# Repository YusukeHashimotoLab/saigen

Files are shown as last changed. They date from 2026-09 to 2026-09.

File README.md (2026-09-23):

# SAIGEN

**SAIGEN** — **S**tandardized **A**utomation **I**nfrastructure for **G**eneralizable
**E**xperiment reproductio**N** (also *saigen*, 再現, Japanese for "reproduction").

A simple, easy-to-introduce, open-source platform for automated materials-synthesis
experiments, focusing on **reliable automation and quantitative process recording**
rather than full autonomy.

Repository: https://github.com/YusukeHashimotoLab/saigen

A manuscript describing the platform and its ZIF-8 demonstration is in preparation
(working title: *Quantitative control and improved reproducibility of materials
synthesis processes using an automated experimentation platform*). It is referred to
as "the paper" throughout this repository; a citation will be added here once it is
available.
<!-- TODO: add the citation / DOI when the manuscript is published, and add a
     preferred-citation block to CITATION.cff. -->

The platform combines commercially available instruments (robot arms, electric
pipettes, web cameras, an electronic balance) with 3D-printed fixtures, and operates
them with control code generated by an AI agent based on a large language model (LLM).
As a demonstration, ZIF-8 (a metal–organic framework) was synthesized with a
two-solution mixing system, and the dependence of its particle size distribution on
the solution dispensing speed was quantified and reproduced.

**Video:** the two-solution mixing system built on this platform, in operation:
https://youtu.be/5X2-4LuQfns

## Repository layout

| Path | Contents |
|---|---|
| `src/agent/` | AI agent that generates JSON experimental flows from natural language (Gemini API or any OpenAI-compatible endpoint) and the preset flows |
| `src/devices/` | Control drivers for each instrument (robot arm, electric pipette, hot-plate stirrer, electronic balance, webcam) and the safety wrapper the flows run through |
| `src/flow/` | Schema, validator, executor and command-line runner for the JSON experimental flow format |
| `src/gui/` | Browser-based GUI for parameter input and flow confirmation |
| `src/voice/` | Voice input (whisper-large-v3-turbo) |
| `src/monitoring/` | IoT sensor logging (Raspberry Pi + Environment Sensor HAT) and process cameras |
| `src/imaging/` | Appearance-imaging system: NEEWER RGB62 light + Logitech C920n camera control, white/red/green/blue capture sequence, cropped-image comparison and depth-direction transmitted-light profiles (paper Figure 6) |
| `detection/` | Object detection based on YOLOv8 — **kept separate for licensing reasons, see below** |
| `cad/` | CAD design bank of 3D-printable experimental components (STL + editable Fusion 360 sources) |
| `docs/` | Bill of materials, setup guide, experimental-flow format reference, spreadsheet-input guide, guide to adding an instrument |
| `examples/zif8/` | Sample experimental flows of the ZIF-8 demonstration (JSON equivalents of the spreadsheet sequence) and monitoring CSV templates |
| `examples/microscope/` | Example flow that photographs the product with the USB digital microscope (`capture_microscope`) |
| `examples/dispensing_stability/` | Measured data of the 100-shot dispensing-repeatability test and the script that recorded it |

## Getting started

1. See [`docs/bom.md`](docs/bom.md) for the full list of hardware used.
2. Print the fixtures in `cad/` (STL files; the Fusion 360 sources are included for
   modification — see [`cad/README.md`](cad/README.md)).
3. Follow [`docs/setup.md`](docs/setup.md) to connect the instruments to the control PC.
4. Copy `config.example.yaml` to `config.yaml` and set the COM ports and workspace
   limits of your own cell; copy `.env.example` to `.env` and set your API keys.
   **Never commit `.env` or `config.yaml`.**
5. Install the Python dependencies: `pip install -r requirements.txt`
   (module-specific notes, e.g. for the imaging system, are in each `src/<module>/README.md`).
   Check the installation with `pytest tests/` — the suite needs no hardware.
6. After every power-on, home each arm once so the firmware's joint angles match the
   real arm (`python -m src.devices.dobot.home_dobot --robot 1 --mock` to rehearse,
   then without `--mock`; the arm sweeps to its joint-1 end stop, so clear the area).
   Then dry-run a flow without hardware, then run it for real. The ZIF-8 examples are the
   JSON equivalents of the spreadsheet sequence in step 7, which is the path the
   paper's batches were actually run with:

   ```bash
   python -m src.flow.run_flow examples/zif8/zif8_two_solution_mixing_speed5.json --mock
   python -m src.flow.run_flow examples/zif8/zif8_two_solution_mixing_speed5.json
   ```

   Every move is checked against the `workspace` limits in `config.yaml` before the
   robot is commanded — in `--mock` mode too. Ctrl+C is an emergency stop: the arm
   halts where it is rather than driving home. Each run leaves
   `logs/<date>/<flow>_<time>/` with `run.log`, `measurements.csv`, `summary.md`,
   `metadata.json` and a copy of the flow; add `--no-record` to skip the sensor-CSV
   and video recording that real runs start by default.

7. Or set the parameters in a spreadsheet — **this is the path used for the paper's
   ZIF-8 experiments**: the two-solution mixing experiment (shown in the
   [video](https://youtu.be/5X2-4LuQfns) above) runs from a
   `parameter,value,note` CSV, with no JSON at all:

   ```bash
   cp src/flow/csv_runner/control.example.csv src/flow/csv_runner/control.csv
   python -m src.flow.csv_runner.run_csv --mock   # then without --mock for a real run
   ```

   The sheet is range-checked before any device is opened, the generated steps go
   through the same schema and workspace validator as a JSON flow, and the run leaves
   the same log folder; see [`docs/csv-runner.md`](docs/csv-runner.md).

8. Or use the GUI, where flows can also be generated from natural language or voice
   (the reported ZIF-8 batches did not use this path):

   ```bash
   streamlit run src/gui/app.py
   ```

   Ports come from `config.yaml` and stay editable in the sidebar; the flow is
   validated against the same schema before any device is opened, *Mock* runs it
   end to end without hardware, *Stop* aborts through the same emergency-stop path
   as Ctrl+C, and the run leaves the same `logs/<date>/…` folder as the CLI.

## Using SAIGEN with an AI coding agent

The intended way to adopt SAIGEN is to clone (or download) the repository, open it
in an AI coding agent such as Claude Code, Codex or Cursor, and let the agent adapt
it to your hardware in conversation. [`CLAUDE.md`](CLAUDE.md) (identical to
[`AGENTS.md`](AGENTS.md)) tells the agent how the repository is organised, how to
verify changes without hardware, and what it must not do on its own — in particular,
it must never start a real run or loosen the workspace limits without you asking.
A first message that works well:

> Read CLAUDE.md, then help me adapt this platform to my hardware: one Dobot Magician
> on COM3 with a Picus 2 pipette on COM4, a BCE8221 balance on COM8 and no second robot.
> Validate and mock-run an example flow when you are done.

Everything the agent does is also available by hand through the steps above.

The flow format is described in [`docs/experimental-flow.md`](docs/experimental-flow.md),
the spreadsheet input in [`docs/csv-runner.md`](docs/csv-runner.md), and adding an
instrument to the platform in [`docs/adding-an-instrument.md`](docs/adding-an-instrument.md); the ZIF-8 flows —
JSON equivalents of the spreadsheet sequence the paper's batches were run with — are in
[`examples/zif8/`](examples/zif8/).

## Licensing

- **Code** (`src/`, `examples/`): MIT License — see [`LICENSE`](LICENSE). Third-party components are listed in [`THIRD_PARTY_NOTICES.md`](THIRD_PARTY_NOTICES.md).
  The robot-arm driver uses [pydobot](https://github.com/luismesas/pydobot)
  (Copyright 2017 Luis Mesas, MIT License) with a small patch in
  `src/devices/dobot/pydobot_patch.py`. The vendor SDK (DobotDll) is **not** used and
  is not included in this repository.
- **CAD models and documentation** (`cad/`, `docs/`): Creative Commons Attribution 4.0
  (CC BY 4.0, https://creativecommons.org/licenses/by/4.0/); the CAD-specific notes are in
  [`cad/README.md`](cad/README.md).
- **Object detection** (`detection/`): depends on [Ultralytics YOLOv8](https://github.com/ultralytics/ultralytics),
  which is licensed under **AGPL-3.0**. This module is therefore isolated from the
  MIT-licensed code and is distributed under AGPL-3.0. The rest of the platform runs
  without it (object detection is an optional monitoring feature).

The fine-tuned YOLOv8 weights and the training images are **not** included in this
repository. `detection/README.md` describes how to fine-tune your own model for your
setup.

## Disclaimer

SAIGEN is research software, shared so that others can reproduce and build on our
work. It is provided "as is", without warranty of any kind; the full terms are in
[`LICENSE`](LICENSE) for the code and in Section 5 of CC BY 4.0 for the CAD models and
documentation. The authors and their institutions accept no liability for injury,
damage to equipment, loss of samples or data, or any other loss arising from its use.

- **It moves hardware and handles chemicals.** A real run drives robot arms, dispenses
  liquids and may heat and stir them. Anyone running it is responsible for their own
  risk assessment, for following the safety rules of their institution and the safety
  data sheets of their reagents, and for supervising the cell while it operates.
- **The safety layer is not a certified safety system.** The workspace validators and
  the emergency stop reduce the chance of a collision inside the limits *you*
  configure. They are not a substitute for guarding, a hardware emergency stop or
  the manufacturers' instructions, and they know nothing about what is actually on
  the bench. Measure your own cell, set your own limits, and always do a mock run
  and a supervised dry run before using reagents.
- **Review generated flows and code.** Flows drafted by the LLM agent, and changes
  made by an AI coding agent, can be wrong in ways that validation does not catch
  (a wrong volume, vial or temperature is still a valid flow). Read them before a
  real run.
- **The CAD models are untested outside our laboratory.** They were designed for our
  instruments and printers; strength, fit, heat resistance and chemical resistance
  depend on your material and print settings and are not guaranteed.
- **No affiliation.** SAIGEN is not affiliated with, endorsed by or supported by the
  manufacturers of the instruments it controls. Product names are trademarks of their
  respective owners. Using this software may fall outside an instrument's intended use
  and may affect its warranty; check with the manufacturer.

## Citing

If you use SAIGEN, please cite the software using the metadata in
[`CITATION.cff`](CITATION.cff) (GitHub's "Cite this repository" button). A paper
citation will be added once the manuscript above is published.

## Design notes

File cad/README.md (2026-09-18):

# CAD design bank

3D-printable experimental components. All models were designed with Autodesk
Fusion 360 and printed on a Bambu Lab X1E.

**License: CC BY 4.0** (https://creativecommons.org/licenses/by/4.0/).
You may share and adapt these models, including commercially, with attribution
to the designers listed below and to the paper (see repository README).

## Gallery

Click a picture to open the STL in GitHub's built-in 3D viewer, where the model
can be rotated and zoomed in the browser.

<table>
<tr>
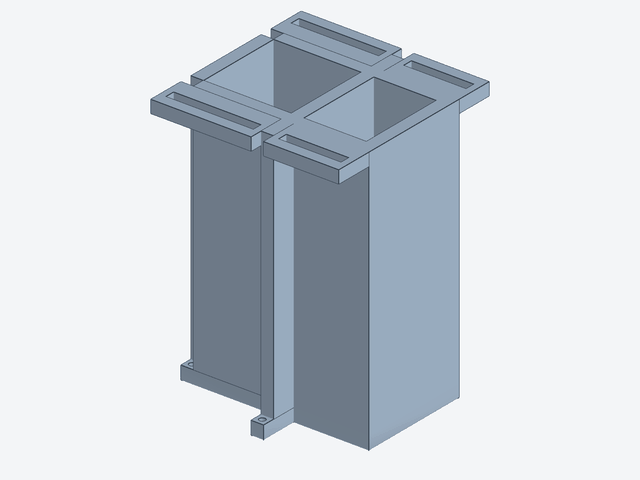
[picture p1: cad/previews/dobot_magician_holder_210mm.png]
Robot-arm pedestal
<td align="center" width="33%"><br><b>Robot-arm pedestal</b><br><sub>150 × 150 × 211 mm · <a href="robot-arm-holder/dobot_magician_holder_210mm.stl">3D view</a></sub></td>
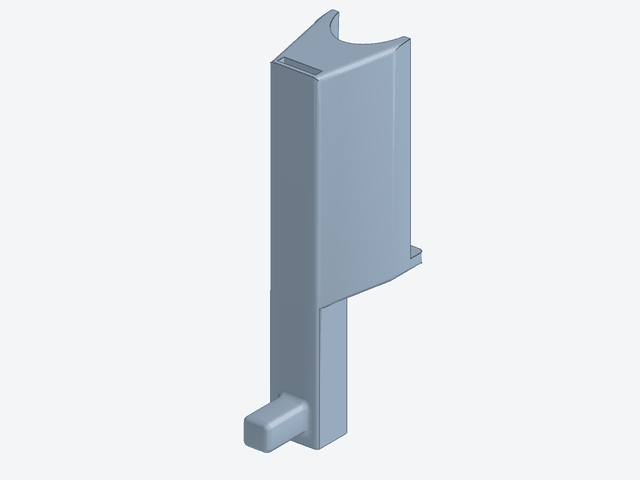
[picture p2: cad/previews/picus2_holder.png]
Pipette holder (Picus 2)
<td align="center" width="33%"><br><b>Pipette holder (Picus 2)</b><br><sub>32 × 67 × 135 mm · <a href="pipette-holder/picus2_holder.stl">3D view</a></sub></td>
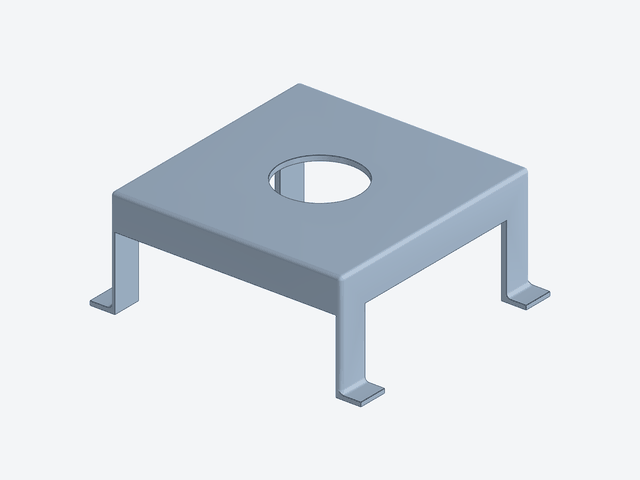
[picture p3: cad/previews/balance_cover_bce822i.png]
Balance cover (BCE822i)
<td align="center" width="33%"><br><b>Balance cover (BCE822i)</b><br><sub>275 × 240 × 109 mm · <a href="balance-cover/balance_cover_bce822i.stl">3D view</a></sub></td>
</tr>
<tr>
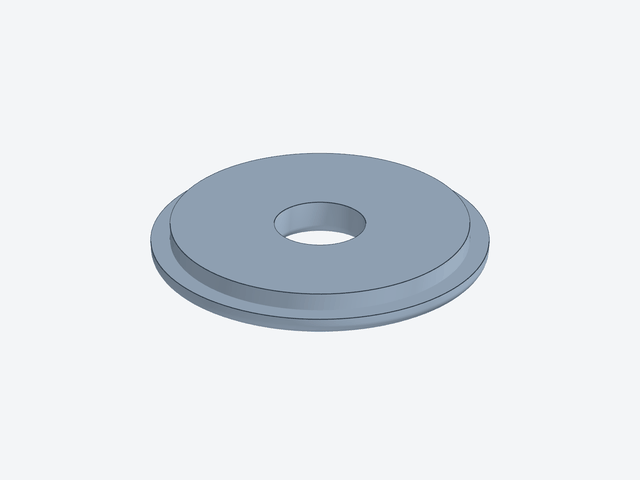
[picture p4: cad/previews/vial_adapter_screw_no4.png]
Adapter: No. 4 screw-cap vial
<td align="center" width="33%"><br><b>Adapter: No. 4 screw-cap vial</b><br><sub>92 × 92 × 10 mm · <a href="balance-cover/adapters/vial_adapter_screw_no4.stl">3D view</a></sub></td>
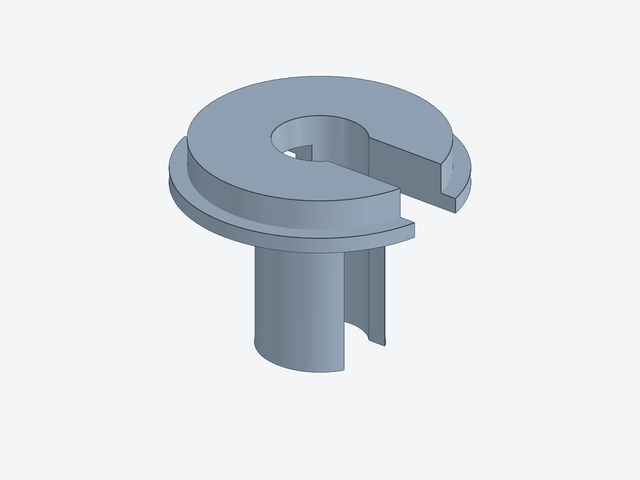
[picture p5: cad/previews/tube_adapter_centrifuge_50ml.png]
Adapter: 50 mL centrifuge tube
<td align="center" width="33%"><br><b>Adapter: 50 mL centrifuge tube</b><br><sub>90 × 92 × 70 mm · <a href="balance-cover/adapters/tube_adapter_centrifuge_50ml.stl">3D view</a></sub></td>
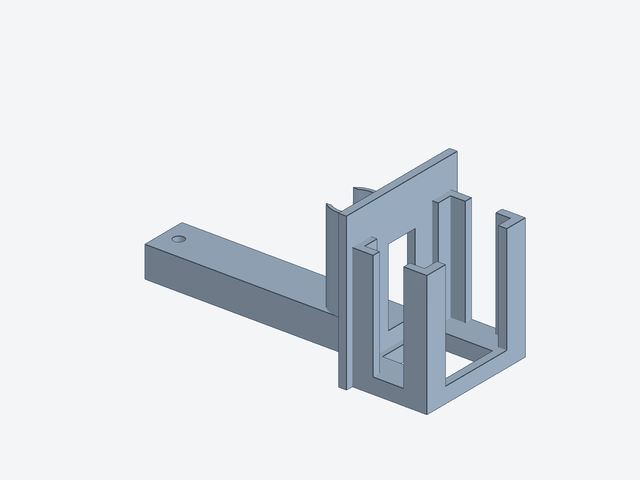
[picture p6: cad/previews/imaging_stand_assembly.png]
Imaging stand
<td align="center" width="33%"><br><b>Imaging stand</b><br><sub>204 × 90 × 100 mm · <a href="imaging-stand/imaging_stand_assembly.stl">3D view</a></sub></td>
</tr>
<tr>
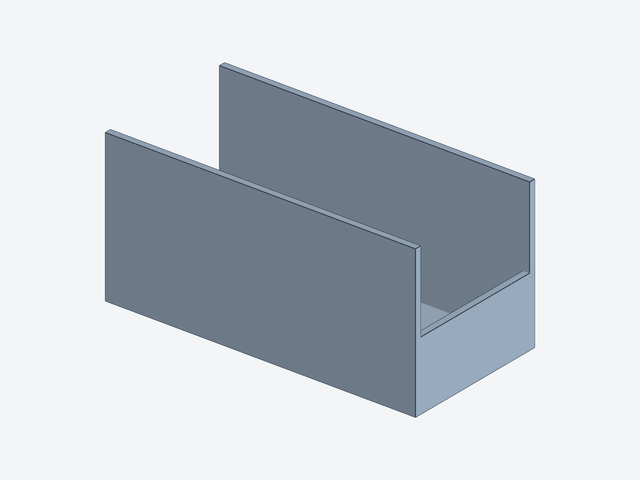
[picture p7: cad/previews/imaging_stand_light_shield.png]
Imaging-stand light shield
<td align="center" width="33%"><br><b>Imaging-stand light shield</b><br><sub>250 × 120 × 120 mm · <a href="imaging-stand/imaging_stand_light_shield.stl">3D view</a></sub></td>
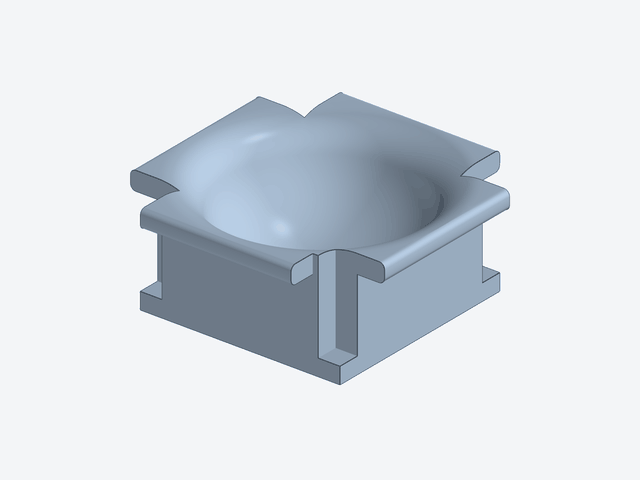
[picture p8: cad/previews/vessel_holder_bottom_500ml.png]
Vessel holder, base (500 mL)
<td align="center" width="33%"><br><b>Vessel holder, base (500 mL)</b><br><sub>140 × 140 × 59 mm · <a href="vessel-holder/vessel_holder_bottom_500ml.stl">3D view</a></sub></td>
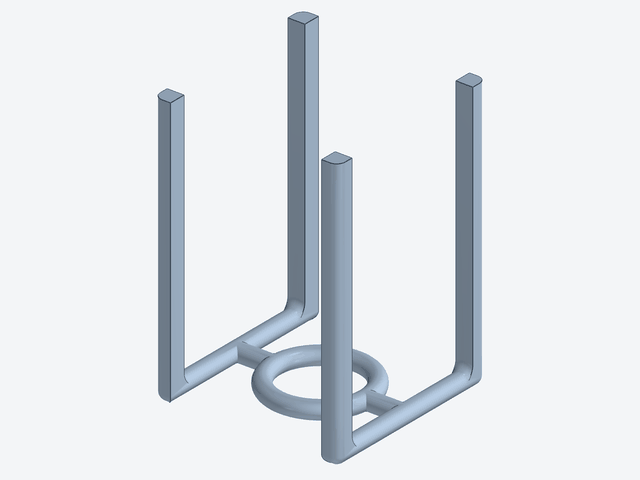
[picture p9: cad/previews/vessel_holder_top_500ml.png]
Vessel holder, upper frame (500 mL)
<td align="center" width="33%"><br><b>Vessel holder, upper frame (500 mL)</b><br><sub>110 × 110 × 160 mm · <a href="vessel-holder/vessel_holder_top_500ml.stl">3D view</a></sub></td>
</tr>
</table>

<p align="center">
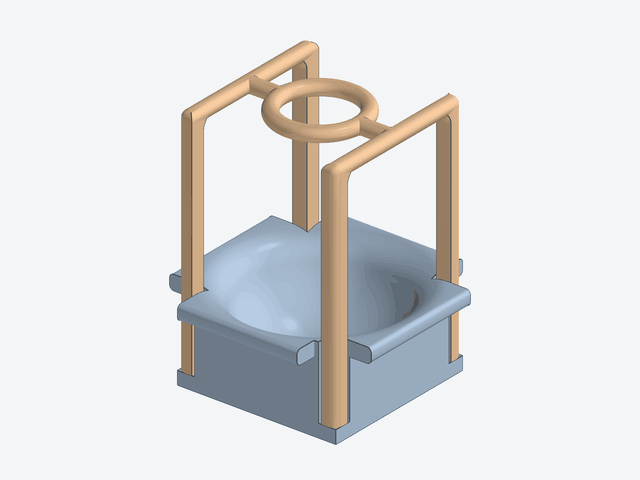
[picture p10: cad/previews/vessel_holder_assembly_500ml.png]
Vessel holder assembled
<br>
<sub>Vessel holder assembled: the upper frame (shown in a second colour) is turned
over and its four posts slide down the corner grooves of the base.</sub>
</p>

## Designers

| Designer | Affiliation | Contact | Components |
|---|---|---|---|
| Takaya Muramoto (村元貴哉) | Graduate School of Engineering, Tohoku University | muramoto.takaya.s1@dc.tohoku.ac.jp | `pipette-holder/` |
| Yusuke Hashimoto (橋本佑介) | Frontier Research Institute for Interdisciplinary Sciences, Tohoku University | yusuke.hashimoto.b8@tohoku.ac.jp | `robot-arm-holder/`, `balance-cover/` (cover and adapters), `imaging-stand/` |

Questions about a model, or corrections to it, go to its designer.

## Components

Every part is provided as a binary STL (millimetres, exported from Fusion 360),
ready to slice, and — where available — as the editable Fusion 360 source.
Bounding boxes are taken from the meshes.

| Directory | Component | Print file | Editable source | Size X × Y × Z (mm) | Designer |
|---|---|---|---|---|---|
| `robot-arm-holder/` | Pedestal that fixes the robot arm (Dobot Magician) to the bench and raises it by 210 mm | `dobot_magician_holder_210mm.stl` | `dobot_magician_holder_210mm.f3d` | 150 × 150 × 211 | Y. Hashimoto |
| `pipette-holder/` | Holder fixing the electric pipette (Sartorius Picus 2) to the robot arm tip | `picus2_holder.stl` | `picus2_holder.f3d` | 32 × 67 × 135 | T. Muramoto |
| `balance-cover/` | Liquid-splash cover for the electronic balance (Sartorius BCE822i), with windshield; its top plate has a Ø82 mm opening for the vessel adapters below | `balance_cover_bce822i.stl` | `balance_cover_bce822i.f3d` | 275 × 240 × 109 | Y. Hashimoto |
| `balance-cover/adapters/` | Vessel adapter for the cover opening: ring for a No. 4 screw-cap vial (13.5 mL; e.g. AS ONE 9-852-06), Ø25 mm chamfered hole | `vial_adapter_screw_no4.stl` | `vial_adapter_screw_no4.f3d` | 92 × 92 × 10 | Y. Hashimoto |
| `balance-cover/adapters/` | Vessel adapter for the cover opening: sleeve for a 50 mL centrifuge tube, Ø30 mm bore | `tube_adapter_centrifuge_50ml.stl` | `tube_adapter_centrifuge_50ml.f3d` | 90 × 92 × 70 | Y. Hashimoto |
| `imaging-stand/` | Holding stand for the appearance-imaging system (light, sample, camera) | `imaging_stand_assembly.stl` (one mesh of the whole assembly) | `imaging_stand_assembly.f3z` (Fusion archive: stand, assembly and light fixture designs) | 204 × 90 × 100 | Y. Hashimoto |
| `imaging-stand/` | Light shield placed over the imaging stand | `imaging_stand_light_shield.stl` | `imaging_stand_light_shield.f3d` | 250 × 120 × 120 | Y. Hashimoto |
| `vessel-holder/` | Two-part holder for a 500 mL round-bottom vessel, base: block with a spherical seat (Ø105 mm) and a groove at each corner for the posts of the upper frame | `vessel_holder_bottom_500ml.stl` | `vessel_holder_bottom_500ml.f3d` | 140 × 140 × 59 | <!-- TODO: designer --> |
| `vessel-holder/` | Two-part holder for a 500 mL round-bottom vessel, upper frame: four 10 mm posts joined by a ring (Ø44 mm bore) that surrounds the vessel neck. The frame gives a robot arm or a lift something to hook, so that the holder can be carried with the vessel in it; exported ring-down, used ring-up | `vessel_holder_top_500ml.stl` | `vessel_holder_top_500ml.f3d` | 110 × 110 × 160 | <!-- TODO: designer --> |

Notes:

- The two vessel adapters share the same seat: a Ø92 mm flange resting on the top
  plate of the balance cover and a Ø81 mm spigot that drops into its Ø82 mm opening,
  so they are interchangeable without modifying the cover. Print one per vessel
  type you use.
- `.f3d` is a single Fusion 360 design; `.f3z` is a Fusion 360 archive that bundles
  an assembly with the designs it references. Open either with *File → Open* in
  Fusion 360 (upload to your project).
- The meshes were checked to be closed (no open edges). `dobot_magician_holder_210mm.stl`
  is exported from a multi-body design, so a few internal faces are shared between
  touching bodies; slicers merge these, but re-export from the `.f3d` if your tool
  complains about non-manifold edges.
- The original file names were Japanese; they were renamed to ASCII for portability.
  Same geometry.
- The pictures in `previews/` are rendered from the STL files by
  [`tools/render_previews.py`](tools/render_previews.py) (needs `pyvista` and `pillow`);
  re-run it after adding or changing a part.
- The upper frame of the vessel holder rests on the 9 mm ledges at the foot of the
  corner grooves, which puts its ring about 160 mm above the bench. A round-bottom
  vessel cannot stand or be gripped on its own; the frame is the handling point
  when the vessel is moved by a robot arm or a lift.
- STEP exports are not included; export them from the `.f3d` / `.f3z` sources if you
  need a neutral format.

<!-- TODO: add recommended print settings (material, layer height, infill) per component. -->

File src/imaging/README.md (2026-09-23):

# Imaging module

Appearance-imaging system for SAIGEN, the automated experimentation platform (see the
[repository README](../../README.md) for the manuscript in preparation that this
module's results belong to). It backlights a sample vial with an RGB light,
photographs it under white, red, green and blue illumination with a fixed
camera, and turns those photographs into cropped side-by-side comparisons and
depth-resolved transmitted-light intensity profiles — the material behind the
paper's "Imaging system for appearance evaluation" section and Figure 6.

## System configuration

### Hardware

| Component | Model | Interface | Notes |
|---|---|---|---|
| Light | NEEWER RGB62 | Bluetooth LE | White (CCT) and single-colour (HSI) modes; controlled by [`neewer_light.py`](neewer_light.py) |
| Camera | Logitech C920n (HD Pro Webcam C920) | USB | Video + control abstracted by [`hw.py`](hw.py) |
| Holding stand | 3D-printed | — | Fixes the relative positions of light, vial and camera; STL and Fusion 360 sources in [`cad/imaging-stand/`](../../cad/imaging-stand/), together with a light shield placed over the stand |
| Control PC | — | — | Runs `camera_server.py`, `acquire.py`, `make_panel.py` |

See [`docs/bom.md`](../../docs/bom.md) for the full platform bill of materials.

### Geometry

The stand holds the light, sample vial and camera on one fixed optical axis so
every photograph is a backlit transmission image of the same region:

```
 NEEWER RGB62        sample vial            Logitech C920n
 (backlight)  -->  (screw-top vial,   -->  (USB, fixed focus
                    suspension below         and exposure)
                    clear supernatant)
   |____________________|____________________|
        all three fixed by the stand (cad/imaging-stand/)
```

### Software-fixed conditions

Imaging conditions are fixed in software rather than by hand, so repeated
photographs are comparable:

- **Camera** — [`config/camera_reference.json`](config/camera_reference.json)
  is the single source of truth: exposure 20 (macOS `exposure-time-abs`
  units; logged Windows equivalent `-9`), gain 0, focus 180, white balance
  4600 K manual. It stores this once per platform (macOS `uvc-util` control
  names under `"reference"`, Windows logical names under `"win32"`), applied
  through `hw.py`'s logical control names; `camera_server.py`'s `/api/health`
  and the acquisition scripts check the live camera against it. Every run
  records the settings **read back from the camera** at capture time
  (`camera_settings` in `summary.json`), not these reference constants.
- **Light** — [`config/light_reference.json`](config/light_reference.json)
  documents the illumination conditions used by `acquire.py`: a white CCT
  shot at 5600 K (used only for detecting the vial geometry; its brightness
  is auto-swept unless fixed with `--white-intensity`), and three HSI
  (single-colour) shots at hue 0° / 120° / 240° (red / green / blue), each at
  1 % intensity. This file is not read by any module at run time — it is a
  human-readable record of constants that are hard-coded in `acquire.py`.

**Two hard rules, both established by measurement on the C920:**

1. **White balance must stay manual at 4600 K. Never switch it back to
   auto.** The C920 has slow, hidden internal white-balance state; every time
   it is switched between auto and manual it settles into a different,
   non-reproducible colour state. Only an uninterrupted manual 4600 K holds a
   consistent colour balance.
2. **Changing exposure while the camera server's stream is running has no
   effect on the frames it serves.** The control write succeeds and reads
   back correctly, but the live MJPEG stream keeps using the exposure that
   was in effect when it started. To change exposure: set the new value,
   then restart `camera_server.py`. Adjusting brightness *during* a
   measurement should be done on the light, not the camera.

The three illumination wavelengths (625 / 525 / 465 nm) are the LED's
**nominal** values, not independently measured (±10-15 nm uncertainty); this
does not affect relative or time-series comparisons. Each single-colour LED
saturates its own dominant camera channel (red→R, green→G, blue→B) even at
1 % intensity, so photometry is always done on the **secondary** channel
(red→G, green→B, blue→G) — see `acquire.py`'s `COLORS` table and
`od_profile()`.

## Module map

| File | Role |
|---|---|
| [`paths.py`](paths.py) | Shared directory layout (`IMAGING_DATA_DIR`, `config/`, `examples/`) and `uvc-util` path resolution |
| [`hw.py`](hw.py) | Platform abstraction for the camera (macOS: ffmpeg + uvc-util; Windows: OpenCV/DirectShow) and the cross-platform measurement file lock |
| [`neewer_light.py`](neewer_light.py) | BLE control of the NEEWER RGB62 (CCT and HSI modes; macOS CoreBluetooth / Windows WinRT+bleak backends) |
| [`capture.py`](capture.py) | Thin HTTP client used by `acquire.py` to trigger captures and read/write camera controls through `camera_server.py` |
| [`camera_server.py`](camera_server.py) + [`static/`](static/) | Local web server (port 8799): live preview, camera/light controls, spot-measurement launcher, analysis viewer, and the HTML/JS front end |
| [`acquire.py`](acquire.py) | Capture sequence (white → red → green → blue) and the optical-density analysis (`od_profile`, sediment-front detection, figure generation) |
| [`geometry.py`](geometry.py) | Vial geometry detection from a white backlit photo (meniscus, cap, body, liquid bottom) |
| [`make_panel.py`](make_panel.py) | Publication panel figure: four cropped photographs plus the depth-resolved transmittance/OD curve |
| [`config/`](config/) | `camera_reference.json` (single source of truth for camera settings), `camera_local.example.json` (per-PC camera selection template), `light_reference.json` (documentation of the light constants) |
| [`examples/`](examples/) | One complete example run (see below) |

## Installation

From the repository root:

```bash
pip install -r requirements.txt
```

Platform-specific notes for this module:

- **macOS** — video comes from `ffmpeg` (AVFoundation) and camera control
  from `uvc-util`; both are external executables, **not bundled** here.
  Install `ffmpeg` with `brew install ffmpeg`; build `uvc-util` from
  [github.com/jtfrey/uvc-util](https://github.com/jtfrey/uvc-util) and put it
  on `PATH`, or point the `UVC_UTIL` environment variable at the binary (see
  `paths.uvc_util_path()`). The light backend uses PyObjC (`pyobjc-framework-CoreBluetooth`,
  `pyobjc-framework-libdispatch`), which `requirements.txt` installs on macOS only.
- **Windows** — video and camera control both go through OpenCV's DirectShow
  backend, which is why `requirements.txt` pins `opencv-python==4.12.0.88`:
  4.13+ (including 5.0) breaks get/set of `CAP_PROP_WHITE_BALANCE_BLUE_U` on
  the C920, the property used to hold the required manual 4600 K white
  balance. `pygrabber` (already listed) enumerates DirectShow devices and
  pulls in `comtypes` automatically. The light backend prefers piggybacking
  on an already-connected device via the `winrt` packages (not pinned) and
  falls back automatically to scanning with `bleak` (already listed) if they
  are absent. On a PC with more than one webcam, copy
  `config/camera_local.example.json` to `config/camera_local.json`
  (git-ignored) and set `win32_device_name`/`win32_device_path` to pick the
  C920 unambiguously — `hw.py` refuses to start on zero or multiple matches.
- **macOS camera selection** — ffmpeg opens the camera by name
  (`HD Pro Webcam C920`) and `hw.py` looks up the `uvc-util` index of that
  same name (`uvc-util -d`), so controls always go to the streamed camera;
  it refuses to start if the name is missing or matches more than one
  device.
- **The light** must be powered on before starting `camera_server.py`. On
  macOS, `neewer_light.py` piggybacks onto an existing BLE connection rather
  than opening its own, so it can share a connection already held by the
  NEEWER Control Center app instead of competing with it. If more than one
  NEEWER light is reachable, `neewer_light.py` refuses to guess: set
  `NEEWER_DEVICE_ID` in the repository's `.env` (or the environment) to part
  of the device id shown in the error message (macOS: peripheral UUID;
  Windows: WinRT device id or Bluetooth address). Every BLE write is
  checked; a device error or a missing acknowledgement aborts the command.
- **`IMAGING_DATA_DIR`** (environment variable) sets where captured photos
  and analysis output go. Default: `imaging_data/` at the repository root
  (`photos/` and `analysis/` subdirectories; see `paths.py`). The location is
  anchored to the module file, not to the current directory, so the camera
  server and a hand-run `acquire.py` always write to the same place. A
  relative value is resolved against the directory the server was started
  from, and the server passes the resolved path (and its actual `--port`,
  as `IMAGING_SERVER_URL`) to the `acquire.py` child it launches.

## Usage

### 1. Start the camera server

```bash
python camera_server.py
```

Open `http://localhost:8799`. The page has five tabs:

- **Camera** — sliders for exposure, gain, focus and white balance (Kelvin),
  auto-exposure/auto-focus/auto-white-balance toggles, and a manual
  **Capture** button; a warning banner reminds you to keep white balance
  manual at 4600 K, and flags that exposure changes need a server restart to
  reach the live preview. While a measurement holds the lock, control writes
  from this tab (or any other client) are refused with HTTP 409; only the
  running acquisition, which registers an owner token, may write.
- **Light** — On/Off, and either White (CCT: brightness + colour temperature)
  or Monochrome (HSI: hue + saturation + brightness, with quick Red 625 /
  Green 525 / Blue 465 buttons) control.
- **Measure** — a named spot measurement: Full (white+RGB) or White-only
  mode, folder and sample name, and toggles for a locked frame, fixed
  monochromatic LED intensity, or fixed white LED intensity (white-only
  mode). This is the UI front end for `acquire.py`, run as a subprocess and
  polled via `/api/spectral/status`.
- **Analysis** — a Refresh button and the most recent run's `spectral.png`.
- **Conditions** — one-shot frame (geometry) calibration, and named presets
  that save/apply/verify a full camera+light+geometry configuration.
  Applying a preset checks every camera write and reads the settings back;
  a failed write or a differing read-back is reported and the light and
  geometry are left untouched. If the stream is stale afterwards (macOS),
  the response says the server must be restarted before measuring: per
  rule 2 above, neither the live view nor captured photos see the change
  until then.

### 2. Apply and verify the reference camera settings

Set the camera to the values in `config/camera_reference.json` (exposure 20 /
gain 0 / focus 180 / white balance manual 4600 K) using the Camera tab or the
`/api/control` endpoint, then confirm with:

```bash
curl http://localhost:8799/api/health
```

`matches_reference` should be `true`; `mismatches` lists any control that
differs from `camera_reference.json`, and `stream_settings_stale` flags the
"exposure changed but the stream didn't update" condition described above.

### 3. Acquire a run

```bash
python acquire.py --folder <experiment> --name <sample>
```

This drives the light through white → red → green → blue, capturing one
photo per step through the running `camera_server.py`, and writes the run to
`<IMAGING_DATA_DIR>/photos/<experiment>/<sample>/`. Before the first photo it
fixes and reads back the white balance, then queries `/api/health` and
**aborts if the stream is stale** (settings changed after the stream
started, e.g. white balance switched from auto on this run — restart the
server and run again), if there is no fresh frame, or if the controls
cannot be read. A mismatch against `camera_reference.json` is only a
warning (the reference exposure depends on the sample) but is recorded. Useful options (see
`python acquire.py --help` for the full list):

| Option | Effect |
|---|---|
| `--mode {full,white}` | `full` (default): white + red/green/blue, ~3-wavelength OD. `white`: a single white shot only, giving per-camera-channel (R/G/B) OD — quicker, but only valid for named runs |
| `--white-intensity PCT` | Fix the white-shot LED intensity (white-only mode only) so multiple samples are photographed under identical illumination, for photo comparison or absolute-transmittance comparison |
| `--fixed-intensity` | Disable automatic monochromatic-LED intensity adjustment and hold it at `--intensity` (for cross-sample absolute comparison) |
| `--calibrate` | Detect the vial geometry once from a white reference and save it as a locked frame |
| `--locked` | Skip per-run geometry auto-detection and reuse the locked frame (for comparing swapped-in samples without shifts in field of view) |
| `--intensity`, `--restore` | Initial monochromatic LED intensity (default 1 %) and the light state to leave the light in when done (default: off) |

### 4. Run directory format

Each run directory contains:

| File | Contents |
|---|---|
| `ref_white.jpg` | White-light reference photo (geometry detection; also the photometry image itself in white-only mode) |
| `shot_red.jpg`, `shot_green.jpg`, `shot_blue.jpg` | Monochromatic captures (full mode only) |
| `profiles.csv` | Per-row optical density, one column per wavelength/channel (`od_625`/`od_525`/`od_465` in full mode, `od_R`/`od_G`/`od_B` in white-only mode), each followed by `od_<label>_cap`, the uncorrected profile computed with the cap pedestal alone (identical when `pedestal_mode` is `cap`) |
| `spectral.png` | OD-vs-depth figure generated by `acquire.py` at capture time |
| `summary.json` | Geometry (`meniscus_y`, `liquid_bottom_y`, `body_x0`/`x1`, `fill_fraction`), per-wavelength intensity/channel/warning plus `pedestal_rule`, `i0` and `analysis_warning`, `sediment_front_y`, `white_balance_fixed` (commanded), `camera_settings` (read back before the first photo), `camera_settings_after` / `camera_settings_changed` (read back after the last), `camera_device`, `camera_matches_reference`/`camera_mismatches`, and measured headspace brightness used to cross-check actual light intensity. Written before the figure, so a plotting failure never loses it; never contains NaN/inf |

### 5. Make the publication panel

```bash
python make_panel.py examples/zif8_vial_5s --out panels
```

Outputs `<run_dir name>_panel.png` (300 dpi), `_panel.pdf`, and a draft
`_caption.md`, all under `--out` (default `./panels`) — `make_panel.py` never
writes into the run directory itself. Options (`python make_panel.py --help`):

| Option | Effect |
|---|---|
| `--y {transmittance,od}` | Right-panel x-axis: transmittance `T = 10^-OD` (default) or OD directly |
| `--with-white` | Also draw the white (G-channel) curve in the depth panel; omitted by default |
| `--mm-per-px MM` | Show the depth axis in millimetres (5 mm steps) instead of pixel rows |

The panel shows four cropped photographs (white, 625, 525, 465 nm, cap bottom
to vial bottom, all cropped to the same rectangle) beside a depth-resolved
transmittance/OD curve that shares the same vertical (pixel-row) scale as the
photographs, so visual features in the photos line up with inflections in the
curve. The white photograph is not plotted as a curve by default: its green
channel is saturated over a clear supernatant (the sensor clips before the
signal can be used quantitatively), so it is shown only as a visual
reference; `--with-white` draws it anyway (as a plain solid line). A
clip table for all four channels — per row, the fraction of pixels at
sRGB >= 250 in the inner 60 % of the body columns, summarised over the
liquid rows — is always printed to stdout regardless of that flag.

The draft caption is built from the run's `summary.json` (LED intensities,
the camera settings and device read back at capture time) and from those
measured clip fractions. Anything the run did not record is written as
"unknown" — e.g. the included example predates the camera read-back, so its
caption says the exposure is unknown rather than quoting the reference.

## Correspondence with paper Figure 6

| Figure 6 panel | Produced by |
|---|---|
| (a) appearance of the imaging system | The stand ([`cad/imaging-stand/`](../../cad/imaging-stand/)) and camera/light hardware described in [System configuration](#system-configuration) above |
| (b) a photograph taken with it | `examples/zif8_vial_5s/ref_white.jpg`, captured by `camera_server.py` via `acquire.py` |
| (c) sample images under white/red/green/blue illumination | The four cropped photo columns produced by `make_panel.py` from that same run |
| (d) depth profile of the transmitted-light intensity | The depth-resolved transmittance/OD curve in `make_panel.py`, computed from `profiles.csv` (written by `acquire.py`'s `od_profile()`) |

One example run is included, [`examples/zif8_vial_5s/`](examples/zif8_vial_5s/)
— the run behind those Figure 6 panels. It is a ZIF-8 suspension (white
sediment below a clear supernatant) synthesised by the platform in a
screw-top vial without stirring, with the second precursor solution
("solution 2") dispensed over 5 s, and photographed on 2026-07-14 at 13:25,
twelve days after synthesis.

It is included as a **worked example of the pipeline, not as a validated
measurement**, and it is not a dispensing-time comparison: it is a single
run at a single dispensing time. Its white reference and its 465 nm channel
are both sensor-clipped over the clear supernatant, and it predates the
reference camera exposure, so absolute transmittance is not comparable
across runs. [`examples/README.md`](examples/README.md) lists these caveats
in full — read it before reusing the numbers.

Figure 8 of the paper (nine vials, three per dispensing time) was **not**
taken with this imaging stand and is not reproduced by anything in this
directory.

## Analysis method

`acquire.py`'s `od_profile()` computes, for each wavelength/channel, a
depth-resolved optical density `OD(y) = -log10(I(y)/I0)`:

- Pixel values come from the secondary colour channel, averaged over the
  inner 60 % of the vial body's columns (avoiding light piped along the
  glass wall), then sRGB-linearised (inverse gamma) before any arithmetic.
- `I0` is the peak transmitted-light level just below the meniscus (past the
  refractive dip the curved liquid surface produces).
- A pedestal (lens flare + dark current) is normally estimated from the dark
  region above the cap; if attenuation is deep enough that the signal pins to
  stray light instead of continuing to fall, a flat low-value window further
  down is used as the floor instead and the curve is truncated there (a
  lower bound on OD only). Which rule chose the pedestal is recorded
  (`pedestal_rule`: `cap`, `flat_window` or `min_then_rise`); the
  minimum-then-rise rule is a heuristic, so it adds an `analysis_warning`,
  and the uncorrected cap-pedestal profile is saved next to the corrected
  one for comparison.
- A uniformly dark image, or a geometry that does not fit the image, gives
  an empty profile with a warning instead of aborting the run.
- The sedimentation front is the shallowest depth where the 625 nm OD rises
  above a fixed threshold for a sustained run of rows.

## Limitations / notes

- The 625 / 525 / 465 nm wavelengths are the LED's nominal values, not
  independently measured (±10-15 nm); verify with a spectrometer or
  diffraction grating before using them quantitatively rather than for
  relative/time-series comparison.
- The geometry detector (`geometry.py`) and the fixed-frame comparison mode
  assume a single vial on a fixed optical axis; it is not a general-purpose
  multi-sample imaging pipeline.
- Camera behaviour (the white-balance hidden state, the live-exposure
  pitfall, per-channel saturation under single-colour LEDs) is specific to
  the Logitech C920/C920n and was established by measurement on that
  camera; a different webcam model may not share these quirks — or may have
  different ones.
- This is a photographic transmission measurement, not a calibrated
  spectrophotometer: optical density values are useful for relative and
  time-series comparison under matched conditions, not as absolute
  extinction coefficients.

## License

MIT, as the rest of `src/` — see [`LICENSE`](../../LICENSE).

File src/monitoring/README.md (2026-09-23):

# Monitoring

IoT environmental sensor logging and process video recording for the automated
synthesis platform. A Raspberry Pi Zero WH + Waveshare Environment Sensor HAT
pushes sensor readings to the control PC, where a small FastAPI service
records them (plus an overhead-camera AprilTag pose track) to CSV; a separate
OpenCV helper records the overhead-camera video itself.

## Overview

```
 ┌────────────────────┐        TCP :50001            ┌───────────────────────────────────┐
 │ Raspberry Pi        │  JSON Lines, ~10 Hz          │ Control PC                          │
 │ pi/pi_sensor_agent  │ ────────────────────────────>│ dashboard/launch_sensor_dashboard   │
 │  (I2C sensor reads)  │                              │  FastAPI :8000  +  TCP server :50001│
 └────────────────────┘                              │                                      │
                                                       │  latest_sensor_data ──┐              │
                                                       │                       ▼              │
                                                       │              recording_loop (100 ms) │
                                                       │                       │              │
                                                       │                       ▼              │
                                                       │              CSV (sensor + tags)     │
                                                       └───────────────────────────────────┘
                    browser (dashboard UI)                       ▲        ▲
                        │  camera frames                          │        │
                        └── POST /api/detect_tags ─────────────────┘        │
                        └── POST /api/upload_video (webm) ───────────────────┘

 src/flow/run_flow.py, src/gui/app.py or any external process
        │
        └── POST /api/start , POST /api/end  ────────► start/stop a recording session

 camera/video_recorder.py  (on the control PC, independent of the dashboard)
        └── OpenCV VideoCapture(camera_index) ──► .mp4 (overhead process video)
```

Two recording paths run independently:

1. **Sensor + AprilTag CSV logging** — `dashboard/launch_sensor_dashboard.py`
   receives sensor pushes over TCP, serves a browser dashboard over HTTP, and
   (while a recording session is active) writes one CSV row per Pi every
   100 ms plus AprilTag pose rows whenever the browser posts a camera frame
   to `/api/detect_tags`.
2. **Overhead video recording** — `camera/video_recorder.py` opens an OpenCV
   `VideoCapture` on the process camera and writes an `.mp4` on its own
   thread. It has no dependency on the dashboard and can be started/stopped
   independently (e.g. from `src/flow/run_flow.py`).

## Measured quantities

| Quantity | Sensor | I2C address | CSV column(s) |
|---|---|---|---|
| Temperature | BME280 | `0x76` | `temperature` (°C) |
| Humidity | BME280 | `0x76` | `humidity` (%RH) |
| Visible + IR light (raw, **not lux**) | TSL25911 | `0x29` | `lux_raw` (channel-0 count) |
| UV | LTR390 | `0x53` | `uvi` (UV index) |
| VOC | SGP40 | `0x59` | `voc_raw` (raw signal, not the VOC index) |
| 3-axis acceleration | ICM20948 | `0x68` | `acc_x`, `acc_y`, `acc_z` (g) |
| 3-axis angular velocity | ICM20948 | `0x68` | `gyro_x`, `gyro_y`, `gyro_z` (deg/s) |

**The magnetometer (AK09916, embedded in the ICM20948 package) is not read in
this version.** Only the ICM20948's accelerometer and gyroscope are used.

**UV column semantics changed on 2026-09-08.** Recordings made before that date
were taken with the LTR390 in ALS mode, in which the UVS data registers never
update, so their `uvi` column is `0` throughout. The Pi agent now initialises
the sensor in UVS mode (20-bit, gain 3, 1000 ms measurement rate) and `uvi`
holds a UV index as a float. The column name is unchanged so older CSV files
remain parseable. Because a 20-bit conversion takes 400 ms, the value updates
about once a second even though the agent samples every 100 ms.

**Humidity recorded before 2026-09-23 is wrong by a factor of 1024.** The Pi
agent's BME280 compensation shifted the Q22.10 result right by 22 bits (which
already gives whole %RH) and then divided by 1024 again, so the `humidity`
column of older recordings holds values between 0 and about 0.098 instead of
0-100 %RH. Multiplying an old value by 1024 recovers the humidity, but only to
1 %RH: the 22-bit shift had already dropped the fractional part, so every
recovered value is a whole number (rounded down). Recordings made with the
fixed agent carry the full resolution of 1/1024 %RH.

**The light column is a raw count, not lux, and was renamed on 2026-09-23.**
The value recorded as `lux` in older files was never lux: it is the TSL25911's
raw channel-0 (visible + IR) ADC count at the power-on gain (1x) and
integration time (100 ms). It is now called `lux_raw`, in the Pi's messages,
in `/api/sensors` and in the CSV. The dashboard still accepts the old `lux` key
from an agent that has not been updated and stores it as `lux_raw`; an old CSV's
`lux` column holds the same quantity.

> **TODO (lux):** a lux value needs channel 1 (IR) as well as channel 0 and the
> gain/integration-time scaling (the counts-per-lux factor from the AMS
> TSL2591 application note, which the datasheet itself does not give). The
> agent reads only channel 0 and leaves the gain/integration at their defaults,
> so it does not compute lux. Add it only together with a reading of channel 1
> (`0xB6`/`0xB7`) and, ideally, a comparison against a reference lux meter.

**Failed sensor reads are `null`, not 0 (from 2026-09-23).** Each message from
the Pi carries an `ok` object with one flag per sensor (`bme280`, `tsl25911`,
`icm20948`, `ltr390`, `sgp40`). A sensor that did not answer, or whose SGP40
reply failed its CRC-8 check, reports `null` and `ok: false`; in the CSV the
cell is left empty. Older agents sent `0` for a failed read, so a `0` in an
old recording may mean "no reading". A sensor that fails to initialise is
retried with backoff (1 s, doubling to 60 s) while the others keep reporting;
the agent exits with status 1 (and systemd restarts it) only if the I2C bus
cannot be opened or no sensor answers at all.

**SGP40 humidity compensation (from 2026-09-23).** The raw VOC signal is now
measured with the BME280's humidity and temperature as compensation instead of
the fixed defaults (50 %RH, 25 °C); if the BME280 reading is missing, the
defaults are still used. `voc_raw` values of older recordings are therefore
not directly comparable with new ones at humidity far from 50 %RH.

## Raspberry Pi setup

1. Flash **Raspberry Pi OS Lite (Bookworm, 32-bit)** to the SD card with
   [Raspberry Pi Imager](https://www.raspberrypi.com/software/). Use the
   Imager's own settings (gear icon / "Edit Settings") to set the hostname,
   create a user, and configure Wi-Fi — **never commit these credentials to
   the repository.**
2. Boot the Pi, SSH in, and enable I2C:
   ```bash
   sudo raspi-config
   # Interface Options -> I2C -> Enable
   ```
3. Install the I2C tools and Python bus library:
   ```bash
   sudo apt update
   sudo apt install -y python3-smbus i2c-tools
   ```
4. Power off the Pi and mount the Waveshare Environment Sensor HAT on the
   40-pin GPIO header.
5. Boot again and verify the sensors are visible on the bus:
   ```bash
   i2cdetect -y 1
   ```
   Expected addresses: `0x29` (TSL25911), `0x53` (LTR390), `0x59` (SGP40),
   `0x68` (ICM20948), `0x76` (BME280).
6. Copy the agent and service files from this repository to the Pi (see
   [Installing the agent](#installing-the-agent) below), or do it manually:
   ```bash
   scp src/monitoring/pi/pi_sensor_agent.py pi@<pi-host>:~/pi_sensor_agent.py
   ```
7. Create `/etc/sensor-agent.env` on the Pi from
   [`pi/sensor-agent.env.example`](pi/sensor-agent.env.example), filling in
   your control PC's address:
   ```bash
   ssh pi@<pi-host> "sudo tee /etc/sensor-agent.env >/dev/null" < src/monitoring/pi/sensor-agent.env.example
   ssh pi@<pi-host> "sudo chmod 600 /etc/sensor-agent.env"
   # then edit SENSOR_AGENT_PC_HOST on the Pi to your PC's real address
   # (and SENSOR_AGENT_TOKEN if the PC sets SENSOR_DASHBOARD_PI_TOKEN)
   ```
8. Install and enable the systemd service:
   ```bash
   ssh pi@<pi-host> "sudo cp ~/sensor-agent.service /etc/systemd/system/ && \
       sudo systemctl daemon-reload && sudo systemctl enable --now sensor-agent"
   ```
9. Check it is running and reconnecting correctly:
   ```bash
   ssh pi@<pi-host> "journalctl -u sensor-agent -f"
   ```

### Installing the agent

[`pi/install_pi_agent.ps1`](pi/install_pi_agent.ps1) automates steps 6-8 from
a Windows control PC:

```powershell
.\src\monitoring\pi\install_pi_agent.ps1 -User pi -HostName raspberrypi.local -PcHost 192.0.2.10
```

This copies `pi_sensor_agent.py`, renders `sensor-agent.service` with `%i`
substituted for the given user, renders `/etc/sensor-agent.env` with the
given `-PcHost`/`-PcPort` (and `-AgentToken`, written as `SENSOR_AGENT_TOKEN`,
if you pass it), and enables the service over SSH. Run it once per
Pi; after that, the agent starts automatically on every boot and reconnects
to the PC whenever the connection drops. Re-run the script (or just update
`/etc/sensor-agent.env` and `systemctl restart sensor-agent`) if the control
PC's address changes.

## Network

- The Pi and the control PC must be reachable on the same LAN. Any LAN
  works — the reference setup used a Windows mobile hotspot hosted by the
  control PC, mainly because it makes the PC's gateway address predictable
  and keeps mDNS (`*.local`) hostname resolution reliable without depending
  on lab infrastructure, but a normal router or switch works identically.
- The Pi's target address is configured on the Pi side, via
  `SENSOR_AGENT_PC_HOST` in `/etc/sensor-agent.env` — **not** hardcoded in
  `pi_sensor_agent.py`. There is no default; the agent exits with an error if
  the variable is unset and no `--host` argument is given.
- The dashboard's web server listens on `127.0.0.1` (loopback only) by
  default — a remote browser cannot reach it and the recording-control API is
  not exposed to the LAN. To open the dashboard from another machine's
  browser:
  1. Set `SENSOR_DASHBOARD_HOST=0.0.0.0` (or a specific LAN IP) in the
     control PC's environment.
  2. Set `SENSOR_DASHBOARD_TOKEN` to a random secret — once set, `/api/start`
     and `/api/end` require it (as an `X-Auth-Token` header), and so do the
     `start_recording` / `stop_recording` commands on the `/ws` WebSocket.
  3. If the browser's URL uses a LAN IP rather than `localhost`, add that IP
     to `SENSOR_DASHBOARD_ALLOWED_HOSTS` (comma-separated) so it passes the
     Host-header allow-list. The same list also gates the WebSocket's `Origin`
     header, so a remote browser will not connect without this step.
  4. Open the dashboard once as `http://<host>:8000/?token=<secret>` so the
     page can authenticate its WebSocket; see [Dashboard security](#dashboard-security).
  5. Allow inbound TCP `8000` (dashboard) and `50001` (Pi sensor pushes)
     through the PC's firewall.
- All dashboard environment variables are listed, with comments, in
  [`dashboard.env.example`](dashboard.env.example).

### Sensor ingestion (TCP :50001)

The sensor listener has to accept connections from the LAN, since the Pi is a
separate host. By default it accepts data from **any** host that can reach the
port, and that data goes into the CSV. Two optional, independent restrictions
(both env vars on the PC):

- `SENSOR_DASHBOARD_PI_ALLOWED_IPS` — comma-separated IPs and/or CIDR
  networks (e.g. `192.0.2.21,192.0.2.22` or `192.0.2.16/28`). A connection
  from any other address is closed before anything is read. Give the Pis
  fixed addresses (a DHCP reservation) if you use this. An entry that is not
  an address makes the dashboard refuse to start.
- `SENSOR_DASHBOARD_PI_TOKEN` — shared secret. The first line of every
  connection must then be `{"type": "auth", "token": "<secret>"}`; the agent
  sends it when `SENSOR_AGENT_TOKEN` is set in `/etc/sensor-agent.env`. A
  connection without it, or with the wrong value, is closed. The token travels
  in clear text, so it keeps out other hosts and misconfigured agents, not an
  attacker who can sniff the LAN.

The dashboard logs a warning at start-up while neither is set. Independently of
both, every message is type-checked before use: numeric readings must be a
number or `null`, `accel`/`gyro` `null` or a list of exactly three numbers or
nulls, and only the known fields are kept. A malformed line is logged and
dropped; the connection and the recording continue.

## Dashboard security

The dashboard can start and stop recordings and choose the directory CSV files
are written to, so the following protections apply to the `/ws` WebSocket as
well as to the HTTP API:

- **Host-header allow-list** (always on). `TrustedHostMiddleware` rejects
  requests whose `Host` is not `localhost`, `127.0.0.1`, `::1`, the configured
  bind address, or an entry of `SENSOR_DASHBOARD_ALLOWED_HOSTS`. This is the
  standard defence against DNS rebinding.
- **WebSocket `Origin` check** (always on). A `/ws` handshake is closed with
  code `1008` unless its `Origin` host is in that same allow-list. Browsers do
  not apply the same-origin policy to WebSockets, so without this check any web
  page the operator happens to visit could open `ws://localhost:8000/ws` and
  drive `update_config` + `start_recording` to write files to a directory of
  its choosing (cross-site WebSocket hijacking). A handshake with **no**
  `Origin` header is a non-browser client (curl, the flow runner, a test) and is
  accepted only from the local machine.
- **Token on recording control and state-changing endpoints.** When
  `SENSOR_DASHBOARD_TOKEN` is set, every endpoint that changes state or writes
  a file requires it as an `X-Auth-Token` header: `POST /api/start`,
  `/api/end`, `/api/upload_video`, `/api/detect_tags` (which appends to the
  tags CSV), `/api/zero_tags` and `/api/clear_zero`. `start_recording` /
  `stop_recording` over `/ws` require it too — either as a `?token=<secret>`
  query parameter on the WebSocket URL or as a `"token"` field in the message.
  The page sends the stored token with all of these. When no token is
  configured (the localhost-only default), the two WebSocket actions are
  restricted to local clients.
- **Same-origin check on state-changing HTTP endpoints** (always on). The six
  endpoints above answer `403` when the request carries an `Origin` (or, if
  absent, a `Referer`) that is not this dashboard's own `scheme://host:port`.
  Without it, any web page open in the operator's browser could submit an
  HTML form to `http://localhost:8000/api/end` (no body needed) and stop a
  running recording, or post junk to the upload/tag endpoints. Requests with
  neither header are non-browser clients (the flow runner, the GUI, curl) and
  pass this check.
- **What is exposed without a token.** With `SENSOR_DASHBOARD_TOKEN` unset,
  any *process on the control PC* (and, if you bind the web server to the
  LAN, any host that can reach it) can start/stop recordings, upload a video
  into the save directory and reset tag zeros through the HTTP API; the
  same-origin check only stops other *web sites* in the browser. The read-only
  endpoints (`/api/status`, `/api/sensors`) never need the token. Set a token
  whenever the PC is shared or the dashboard is bound beyond loopback.
- **Local-only privileged actions** (always on). `update_config`,
  `pick_folder` and `open_folder` are refused for any non-loopback client
  regardless of the token.
- **Upload size limit.** `POST /api/upload_video` stops at 200 MB and returns
  HTTP 413, deleting the partial file; override with
  `SENSOR_DASHBOARD_MAX_UPLOAD_BYTES`.

The browser front end has no token input field. Open the dashboard once as
`http://<host>:8000/?token=<secret>` — `static/app.js` stores the value in
`localStorage` under the key `sensorDashboardToken` and reuses it on every
later visit and reconnect (you can also set that key from the browser console).
Rejected commands are reported back on the WebSocket as
`{"type": "error", "action": ..., "detail": ...}` and appear in the page's log
panel.
- The TCP sensor listener (`SENSOR_DASHBOARD_TCP_HOST`, default `0.0.0.0`)
  listens on all interfaces, since the Pi is necessarily a separate host; see
  [Sensor ingestion](#sensor-ingestion-tcp-50001) for its allow-list and token.
- **Device names are rendered as text.** Hostnames come from mDNS
  announcements, which any host on the LAN can make; the page escapes them
  before inserting them, so a crafted name cannot inject markup or script.

## Running the dashboard on the PC

```bash
pip install -r src/monitoring/requirements.txt
python src/monitoring/dashboard/launch_sensor_dashboard.py
```

This calls `uvicorn.run(app, host=WEB_HOST, port=WEB_PORT)` directly from the
script's `__main__` block (rather than the `uvicorn` CLI), using the host/port
resolved as described above. By default it also opens the dashboard in a
browser about 1.5 s after startup; set `SENSOR_DASHBOARD_HEADLESS=1` to skip
that (e.g. when running on a headless machine or under a process supervisor).

Port numbers come from `src/monitoring/config.yaml` if present, else from
[`config.example.yaml`](config.example.yaml), else from the built-in defaults
`web_port: 8000` / `tcp_port: 50001`. `config.yaml` is gitignored — copy
`config.example.yaml` to `config.yaml` in this directory to override the
ports locally without touching version control. The first of those files that
exists is used; if it cannot be parsed, its top level (or its
`sensor_dashboard` section) is not a mapping, or a port is not an integer in
1-65535, the dashboard refuses to start with a `DashboardConfigError` naming
the file, instead of silently falling back to the defaults (which would leave
the Pis pushing to a port nobody listens on). Whatever `tcp_port` is
configured on the PC must match `SENSOR_AGENT_PC_PORT` in every Pi's
`/etc/sensor-agent.env`.

Recordings are written under `experiment_data/` at the repository root by
default; override with `SENSOR_DASHBOARD_DATA_DIR`.

## Log format

Each recording session produces up to three files in the save directory,
named from the session start time and an optional experiment-name prefix
(from `POST /api/start`'s `experiment_name`, sanitized to `[A-Za-z0-9_-]`):

- `{prefix}session_YYYYMMDD_HHMMSS.csv` — sensor readings
- `{prefix}session_YYYYMMDD_HHMMSS_tags.csv` — AprilTag poses
- `{prefix}session_YYYYMMDD_HHMMSS.webm` — optional, only if the browser's
  in-page webcam recorder was used (`POST /api/upload_video`)

The sensor CSV is written by sampling `latest_sensor_data` (the most recent
message received from each Pi) every 100 ms, regardless of each Pi's own
push rate — so a slow or bursty Pi still produces one row per tick, holding
its last known value. Each row carries both the tick time (`timestamp`) and
the arrival time of the sample it holds (`received_at`, from 2026-09-23), so
a held or stale value is recognisable. See [`examples/zif8/`](../../examples/zif8/) for sample
files (`sensor_session_sample.csv`, `sensor_session_sample_tags.csv`) showing
the older layout (they still show the `lux` column and no `received_at`);
they are placeholders, not measurements from an actual run.

### Sensor CSV columns

| Column | Meaning |
|---|---|
| `timestamp` | Recording tick, ISO 8601, UTC, with offset (e.g. `2026-01-01T03:00:00.000000+00:00`) |
| `received_at` | Arrival time of the sample in this row, ISO 8601, UTC (absent before 2026-09-23) |
| `hostname` | Reporting Pi's hostname |
| `temperature` | °C |
| `humidity` | %RH; divided by 1024 (0-0.098) in every recording made before 2026-09-23, see [Measured quantities](#measured-quantities) |
| `lux_raw` | TSL25911 channel-0 raw count (gain 1x, 100 ms), **not lux**; named `lux` before 2026-09-23, see [Measured quantities](#measured-quantities) |
| `uvi` | UV index (float); `0` in every recording made before 2026-09-08, see [Measured quantities](#measured-quantities) |
| `voc_raw` | VOC, raw sensor signal |
| `acc_x`, `acc_y`, `acc_z` | Acceleration, g |
| `gyro_x`, `gyro_y`, `gyro_z` | Angular velocity, deg/s |

An empty cell is a failed or missing reading (`null` from the Pi).

### Tags CSV columns

| Column | Meaning |
|---|---|
| `timestamp` | ISO 8601, UTC, with offset |
| `tag_id` | Detected AprilTag (36h11) ID |
| `tx_mm`, `ty_mm`, `tz_mm` | Translation relative to the camera, mm |
| `roll`, `pitch`, `yaw` | Rotation relative to the camera, degrees |
| `dx_mm`, `dy_mm`, `dz_mm` | Translation relative to this tag's zero reference, mm (blank if no zero has been set) |
| `droll`, `dpitch`, `dyaw` | Rotation relative to the zero reference, degrees (blank if no zero has been set) |
| `outlier` | `1` if this sample's pose jump was rejected and the previous smoothed pose was held instead, else `0` |

The camera's intrinsics are an approximation (`fx ≈ 0.85 × frame width`), so
absolute `t*_mm` values carry a distance-dependent bias; relative motion and
angles (and the zero-referenced `d*` columns) are the more reliable readout.

## Overhead camera recording

```python
from src.monitoring.camera.video_recorder import VideoRecorder

recorder = VideoRecorder(
    output_path="experiment_data/session_20260101_120000.mp4",
    camera_index=1,   # see config.yaml's video.camera_index
)
recorder.start()
# ... run the experiment ...
saved_path = recorder.stop()
```

`camera_index` is the OpenCV device index for the Logitech C920n mounted
above the setup; it is platform- and machine-dependent (probe with a short
OpenCV script if recordings come from the wrong camera). The recorder runs on
its own background thread and paces frames to the camera's own reported FPS.

The worker thread owns the capture and the writer and releases both itself
when it ends. `stop(timeout=5.0)` signals it and waits; if the worker is still
running at the timeout (typically a `read()` blocked on a camera that went
away), `stop()` does **not** release anything under it, logs an error, sets
`recorder.last_stop_clean = False` and still returns the path; the file is
finalised when the worker eventually returns. After a normal stop,
`last_stop_clean` is `True`.

## HTTP API

The dashboard exposes an HTTP API — used by the GUI (`src/gui/app.py`) and the flow runner to
start and stop recording, and available to any other program on the LAN to
read live sensor values. See [`dashboard/API.md`](dashboard/API.md) for the
full endpoint reference, request/response examples, and authentication
notes.

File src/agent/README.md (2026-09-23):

# `src/agent` — AI agent for experimental-flow generation

Turns a natural-language description of an experiment into a JSON experimental flow
(format: [`docs/experimental-flow.md`](../../docs/experimental-flow.md)) that
`src/flow` validates and executes.

## Files

| File | Role |
|---|---|
| `llm_service.py` | `generate_workflow_from_prompt(text, template=None)` — builds the prompt, calls the LLM, extracts and parses the JSON (one automatic retry if the reply is not valid JSON) |
| `presets/*.json` | Validated flows offered in the GUI and usable as templates for the agent |

## How it works

`SYSTEM_PROMPT` in `llm_service.py` describes the robots (`robot_id` 1–3), every
available action with its parameters and units, three worked examples, and the safety
conventions (return home at the end of each loop and of the flow). The user text is
appended and the model is asked for a single JSON object at temperature 0.

With `template=` (a preset's `template` dict) the model is instructed to change only
the parameters of the given flow and keep the step order — the safest way to derive a
new condition from a procedure already checked on hardware. The reply is then checked
against the template (`check_template_structure`): the same number of steps, the same
`action`, `robot_id` and `loop_id` in the same order. Any structural change raises
`TemplateStructureError` with the offending steps, and the GUI shows the error and
keeps the prompt; a failed generation never loads the unchanged template in its place.

Rotation directions in the prompt are stated from a named viewpoint: positive
`rotate_relative` is counter-clockwise seen from above (+Y), which for an operator
standing in front of the robot and facing it ("operator facing the robot") moves the
arm to the operator's right.

The returned dict is **not** trusted: `src/flow/schema.py` validates it before
anything moves, and the GUI shows it for review first.

## Backends

Selected with `LLM_MODE` in `.env` (see `.env.example`):

| `LLM_MODE` | Variables | Notes |
|---|---|---|
| `gemini` (default) | `GEMINI_API_KEY`, `GEMINI_MODEL` (default `gemini-3.5-flash`) | Uses `google-generativeai`, JSON response mode |
| `openai_compatible` | `LLM_BASE_URL`, `LLM_API_KEY`, `LLM_MODEL` | Any server speaking the OpenAI chat-completions API, e.g. a local inference server |

Keys are read only from the environment / `.env`; nothing is hard-coded.

## Usage

```python
from src.agent.llm_service import generate_workflow_from_prompt

flow = generate_workflow_from_prompt("右に90°回転して70mm下降し、5 mL 排出してホームに戻る")
```

The prompt and the built-in examples are in Japanese; the model handles English
instructions as well.

## Adding an action

1. Add the Pydantic model and register it in `LabRobotAction` (`src/flow/schema.py`).
2. Add the dispatch branch in `src/flow/executor.py`.
3. Describe the action, with one example, in `SYSTEM_PROMPT`.

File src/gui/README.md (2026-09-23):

# `src/gui` — browser-based GUI

A Streamlit app for building, reviewing and running experimental flows without
editing JSON by hand.

```bash
streamlit run src/gui/app.py
```

Opens `http://localhost:8501`.

| file | role |
|---|---|
| `app.py` | the Streamlit UI only: flow canvas, presets, AI/voice input, sidebar, progress |
| `runner.py` | all execution logic, Streamlit-free and unit-tested (`tests/test_gui_runner.py`) |
| `analyze_dispense_log.py` | precision/accuracy statistics for a finished run folder |

`app.py` holds no device code: pressing *Run* hands the flow to `runner.FlowRunner`,
which takes exactly the same path as the CLI (`python -m src.flow.run_flow`), so a
flow behaves identically whether it is started from the browser or the terminal.

## Features

- **Flow canvas** — every step of the current flow as an editable card (parameters,
  `robot_id`, reorder, delete); a toolbox adds new steps.
- **Presets** — load a validated flow from `src/agent/presets/`.
- **AI generation** — describe the experiment in natural language; the agent
  (`src/agent`) returns a flow that is shown in the canvas for review before running.
  Optionally start from a preset and let the agent change only its parameters.
- **Voice input** — microphone button next to each text box; transcription by
  `src/voice`.
- **Validation before execution** — the flow is checked against the Pydantic schema
  (`src/flow/schema.py`) and its loops are expanded *before* any device is opened.
  A flow that fails validation is refused: the errors are listed in the UI (one line
  per offending step) and no `ExperimentSession` is created. Flows arriving from the
  agent, a preset or an uploaded JSON file are validated on arrival and **replace the
  canvas only if they validate**; a rejected flow is kept out of the canvas and shown
  read-only with its errors. The *Validate* button re-checks the current canvas
  (schema, loops and the workspace preflight) without running it. The same workspace
  preflight as the CLI runs before every start. Steps on the canvas that do not pass
  the schema are drawn read-only: drawing never writes defaults or coerced values
  into the flow; values change only when the user edits a widget.
- **Mock by default; real runs are armed explicitly** — ▶ runs in *Mock* (against
  `MockLabRobot` / `MockSharedDevices`, same log folder as a real run, no recording,
  no safety gate). A real run needs the checkbox *実機で実行する* ticked in the current
  browser session **and** approval in a confirmation dialog; the checkbox clears itself
  when a real run starts. The execution panel (Stop / Validate / Run) is drawn before
  the canvas, so an error while drawing the canvas cannot hide the Stop button. While a
  run is active, JSON import, AI generation and all canvas edits are disabled.
- **Stop** — cancels the running flow. Cancellation lands in `ExperimentSession`'s
  abort path, the same one Ctrl+C takes on the CLI: every robot is emergency-stopped,
  all devices are disconnected, and the run folder is finalised with
  `status: aborted`. (There is no separate "emergency stop" that leaves the run
  half-finished behind.)
- **Progress and log** — a progress bar (`n/total` steps) and the step-by-step log,
  including the device-level messages (balance readings, image paths).
- **Monitoring hook** — in Real mode, if the sensor dashboard (`src/monitoring`) is
  reachable at `SENSOR_SERVER_URL` (default `http://localhost:8000`), recording is
  started before the run and stopped after it (only if this run started it — a 409 on
  `/api/start` means someone else's recording, which is left running), and the
  dashboard's `/api/is_safe` check gates every step. Only a JSON `"safe": true`
  passes; anything else (`"false"`, `1`, missing, HTTP error) raises `SafetyAbort`,
  which stops the hardware in place without a go-home move. An unreachable dashboard
  does not block the run.

## Device settings (sidebar)

Ports and the camera index default to **`config.yaml`** in the repository root
(falling back to the tracked `config.example.yaml`), read through `src.config` — the
same source the CLI uses, so the GUI and the CLI cannot drift apart. Edits in the
sidebar apply to the current browser session only; *↺ config.yaml の値に戻す* restores
the file's values. For a permanent change, edit `config.yaml`.

Only the devices the flow actually uses are opened: robots are taken from the
`robot_id` of the steps, the pipette from `aspirate`/`dispense`/`blow_out`, the
balance from `measure_weight`/`tare_scale` and the camera from `capture_and_save`.

## What a run leaves behind

Every run — from the GUI or the CLI, mock or real — creates

```
logs/<date>/<flow name>_<timestamp>/
    run.log               every log line of the run
    <flow>.json           a copy of the flow that was executed
    measurements.csv      one row per step (weight, image path, status, duration)
    dispense_accuracy.csv each dispense paired with the mass weighed after it
    metadata.json         start/end, status, mode (mock/real), robots used, counts
    summary.md            human-readable report
    images/               pictures taken by capture_and_save
```

The folder is shown under the progress bar while the run is in progress.

To get the statistics of a dispensing run (mean, SD, variance, CV as the
repeatability figure, and the bias against the nominal mass as the trueness figure):

```bash
python -m src.gui.analyze_dispense_log logs/<date>/<flow name>_<timestamp>
python -m src.gui.analyze_dispense_log <run folder> --volume 5 --density 0.998
```

It reads `dispense_accuracy.csv` and falls back to the `weight_g` column of
`measurements.csv`, so it works for any run that weighed something.

## How the run is driven (and why)

Streamlit re-runs the whole script on every interaction, so the run cannot simply
block the script — but slicing it into one step per re-run would mean keeping live
device handles in `st.session_state` and re-implementing the safety frame around
them. Instead `FlowRunner` executes the flow in **one background thread with one
asyncio event loop**, entirely inside `ExperimentSession.run()`, and publishes
`ProgressEvent`s on a queue; the Streamlit script drains that queue and re-runs
itself every ~0.4 s while the thread is alive. *Stop* cancels the asyncio task from
the outside. The run thread never touches the Streamlit API, which is also why
`runner.py` can be tested without a browser.

## Requirements

`streamlit`, `streamlit-mic-recorder` (voice button) and the modules in `src/agent`,
`src/voice`, `src/flow`, `src/devices`. The app degrades gracefully: without an LLM
key the AI button shows a hint; without `ffmpeg`/whisper the microphone is hidden.

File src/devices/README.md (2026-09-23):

# `src/devices` — instrument drivers and safety wrapper

Two layers:

- **Drivers** (`dobot/`, `picus2/`, `ika/`, `scale/`, `webcam/`, `microscope/`): thin, device-specific
  classes that speak the instrument's protocol. They know nothing about experiments.
- **Safety wrapper** (`safety/`): the only layer the flow executor and the AI agent
  ever call. It adds workspace limits, pipette volume tracking, retries, settle
  times and logging on top of the drivers.

The AI agent never generates driver-level code; it only chooses *what* to do, and the
wrapper decides *how*.

## Drivers

| Directory | Instrument | Interface | Library | Main class |
|---|---|---|---|---|
| `dobot/` | Dobot Magician robot arm (+ optional rail / conveyor) | USB serial | `pydobot` (+ small patch in `pydobot_patch.py`) | `PyDobotController` |
| `picus2/` | Sartorius Picus 2 electric pipette (10 mL) | USB serial or Bluetooth LE | `pyserial` / `bleak` | `Picus2Controller` |
| `ika/` | IKA RET control-visc hot-plate stirrer | RS-232C | `pyserial` | `IKAController` |
| `scale/` | Sartorius BCE822i (`BCE8221.py`, used in the paper) and A&D EK-610i (`Ek610i.py`, `scale_controller.py`) balances | RS-232C | `pyserial` | `SerialBalance`, `ScaleController` |
| `webcam/` | USB webcam for process photos | UVC | `opencv-python` | `WebcamController` |
| `microscope/` | USB digital microscope for close-up photos (Sanwa Supply 400-CAM106 = Vitiny UM22 in the paper's cell) | UVC (image) + USB serial via CP210x (LED, focus motor, status) | `opencv-python`, `pyserial` | `MicroscopeController` (subclass of `WebcamController`), `UM22SerialController` |

Each directory has its own README (in Japanese) with the command set and a usage
example. Device addresses (COM port, Bluetooth MAC) are always passed in by the
caller; there are no hard-coded addresses.

## Safety wrapper (`safety/`)

| File | Class | Role |
|---|---|---|
| `lab_robot.py` | `LabRobot` | One robot = one arm + optionally one pipette (+ stirrer). Async API used by the executor: `move_xyz`, `move_z`, `move_radial`, `rotate`, `rotate_relative`, `go_home`, `aspirate`, `dispense`, `blow_out`, `move_slider`, `move_conveyer`. Tracks the current pose and the volume held in the tip. |
| `shared_devices.py` | `SharedDevices` | Balance, camera and microscope, shared by all robots: `tare_scale`, `measure_weight`, `capture_and_save`, `capture_microscope`, `set_microscope_led`, `focus_microscope`. |
| `mock_robot.py` | `MockLabRobot`, `MockSharedDevices` | Same interface as `LabRobot` / `SharedDevices` without hardware; used by `--mock` and the GUI's Mock mode. The mock enforces the same workspace limits and the same pipette-volume limits (same exception types), keeps a coherent simulated pose (rotations move X/Y, XYZ moves update joint 1, radial moves follow the current radius) and returns realistic weights, so mock runs produce the same records as real ones. Its start pose is `start_pose=(x, y, z, r)`; the runners take it from `shared_devices.mock_start_pose` in `config.yaml` or `MOCK_START_POSE` (see `docs/setup.md`, section 5). |
| `validators/` | `WorkspaceValidator` | XYZ box and joint-1 angle limits, checked before every move. The limits come from the `workspace` section of `config.yaml` in the repository root (`default_workspace_validator()`); edit that file to match your fixtures. |

Construction:

```python
from src.devices.safety.lab_robot import LabRobot
from src.devices.safety.shared_devices import SharedDevices

async with LabRobot(use_dobot=True, use_picus2=True,
                    dobot_port="COM12", picus2_address="COM4",
                    picus2_connection_type="usb") as robot:
    robot.set_current_position_as_home()
    await robot.move_z(-50)
    await robot.aspirate(volume=5.0, speed=5)
    await robot.move_z(50)
    await robot.go_home()

async with SharedDevices(use_scale=True, scale_port="COM9") as shared:
    await shared.tare_scale()
    grams = await shared.measure_weight(stabilization_count=3)
```

Safety behaviour built into the wrapper:

- `aspirate` refuses to exceed 10 mL in the tip; `dispense` refuses to exceed the
  held volume.
- Every target pose is validated against the workspace limits from `config.yaml`;
  a violation raises `WorkspaceViolationError` before the command is sent.
- `initialize()` raises if any device fails to come up (and disconnects whatever did
  connect) rather than returning a status that a caller could ignore and then drive a
  disconnected arm.
- Every blocking driver call (pydobot moves with `wait=True`, the conveyor's timed
  run) runs in a worker thread, so the event loop stays responsive. If the awaiting
  task is cancelled (Ctrl+C, GUI Stop) while a move is in flight, the wrapper sends
  `force_stop()` at once, waits (at most `stop_wait_timeout`, default 10 s) for the
  driver call to return, and re-raises; the first Ctrl+C halts the arm mid-move.
- After a cancelled or failed move, or an emergency stop, the pose is treated as
  unknown: before the next move the wrapper re-reads it from the arm and requires
  it to be stable (`pose_settle_*`), otherwise the move is refused. A move that was
  interrupted by `emergency_stop()` from another thread raises instead of letting
  the flow continue, and no automatic go-home is attempted after an emergency stop.
- After a cancelled or failed `aspirate` / `dispense` / `blow_out` the held volume
  is unknown (`pipette_volume_known` is False; `pipette_volume` keeps the last
  confirmed value): further `aspirate` / `dispense` calls raise `RuntimeError` until
  `blow_out()` succeeds or `reset_pipette_volume()` is called.
- `emergency_stop()` force-stops the Dobot command queue (the move in progress halts
  immediately, the queue is discarded, the conveyor motors stop) and switches the IKA
  heater/stirrer off. `run_flow.py` calls it on Ctrl+C, and commands no further
  motion afterwards. The Picus 2 driver has no stop command: a stroke in progress
  finishes on the pipette, and the held volume is marked unknown.
- Configurable settle times after moves, pipette actions and balance readings
  (`wait_after_*` keyword arguments).
- Pipette connection is retried five times with back-off.
- `cleanup()` (also on `async with` exit or on error) switches the IKA heater and
  stirrer off (best effort) and then disconnects every device.

## Not included

The vendor DLL-based Dobot driver and the powder-dispenser driver used in other
experiments are not part of this repository; only the `pydobot`-based arm driver is
shipped. `LabRobot(use_powder_dispenser=True)` therefore raises `ImportError`.

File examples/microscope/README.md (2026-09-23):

# USB digital microscope example

`product_closeup.json` switches the microscope's LED ring on at a
non-saturating level (`microscope_led`), runs a single-shot autofocus
(`microscope_focus`), takes one overhead photo with the webcam
(`capture_and_save`) and two close-ups with the USB digital microscope
(`capture_microscope`), switches the LED off and sends Robot 1 home. It is a device check as much as an experiment: it only
succeeds if the arm, the webcam, the microscope camera and the microscope's
control port can all be opened.

The paper's cell uses a Sanwa Supply **400-CAM106**, but any UVC microscope works
the same way: it is a plain USB Video Class camera, so no vendor driver is needed
and OpenCV opens it by its device index. The index is a per-PC value and lives in
`config.yaml`:

```yaml
shared_devices:
  camera_index: 1         # overhead webcam
  microscope_index: 2     # digital microscope (video)
  microscope_port: COM10  # digital microscope (LED control, CP210x serial port)
```

The 400-CAM106 is internally a Vitiny UM22: its single USB cable carries a UVC
camera and a Silicon Labs CP210x serial port for the control MCU. The LED
on/off and brightness go over that serial port (`microscope_led`); the
protocol is documented in `src/devices/microscope/README.md`. A microscope
without such a port can still be used for `capture_microscope`; just leave
`microscope_port` empty and drop the `microscope_led` steps.

To find the indices on Windows, run the driver's self-test; it prints the
DirectShow device names in index order (the 400-CAM106 appears as "UVC Video
Device") and saves one test frame:

```bash
python -m src.devices.microscope.microscope_controller 2
```

Then, as with every flow:

```bash
python -m src.flow.run_flow examples/microscope/product_closeup.json --validate-only
python -m src.flow.run_flow examples/microscope/product_closeup.json --mock
python -m src.flow.run_flow examples/microscope/product_closeup.json          # real; press Enter when asked
```

Images land in the run folder, `logs/<date>/<flow>_<time>/images/`, as
`stepNNN_<time>.jpg` for the webcam and `stepNNN_microscope_<time>.jpg` for the
microscope, and their paths appear in `measurements.csv` and `summary.md`.

A frame that is one flat colour means the lens cap is on, the tip is pressed
against the sample or the LED ring is off; the driver logs a warning but keeps
the image.

Autofocus only converges on a textured target; on a blank field the lens hunts
until `timeout` and the step then falls back to manual mode with
`focus_converged` false. The lens position after each focus step is written to
the `focus_position` column of `measurements.csv`. For a reproducible focus,
record that value once and replay it with
`{"action": "microscope_focus", "mode": "position", "position": <value>}`.

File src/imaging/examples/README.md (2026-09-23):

# Example run

One complete example run, `zif8_vial_5s/`, kept here so that `make_panel.py`
can be tried without a camera. It is the source of the photograph in the
paper's Figure 6(b) and of the panel layout in Figure 6(c, d).

| | |
|---|---|
| Sample | ZIF-8 (a metal-organic framework) suspension — white sediment under a clear supernatant — synthesised by the platform on 2026-07-02 |
| Vessel / mixing | screw-top vial, **not** stirred during synthesis |
| Dispensing | the second precursor solution ("solution 2") dispensed over **5 s** |
| Photographed | 2026-07-14 13:25 (`captured_at` `20260714_132511`), twelve days after synthesis, once the suspension had settled |
| Camera | Logitech C920n, gain 0, focus 180, white balance manual 4600 K; **exposure was still at the older, brighter setting used before this module's reference exposure of 20** (see caveats) |
| Light | NEEWER RGB62 — white 5600 K for geometry, then HSI red/green/blue at 1 % intensity |
| Geometry (auto-detected, not locked) | `meniscus_y` 359, `sediment_front_y` 474, `liquid_bottom_y` 620, body columns 632–744, fill fraction 0.708 |

Contents (one run directory as written by `acquire.py`):

- `ref_white.jpg` — white-light reference photo (used for geometry detection)
- `shot_red.jpg`, `shot_green.jpg`, `shot_blue.jpg` — monochromatic captures
  at nominal 625 / 525 / 465 nm
- `profiles.csv` — per-row optical density (OD) for each wavelength
- `spectral.png` — OD-vs-depth figure generated by `acquire.py`
- `summary.json` — capture metadata (geometry, LED intensity, warnings, etc.)

The `"warning"` strings in `summary.json` were translated to English from the
original Japanese capture logs; no other field was modified.

Render the panel with:

```
python3 make_panel.py examples/zif8_vial_5s --out /tmp/panels
```

(the run directory is resolved relative to the current directory first and
then to `src/imaging/`, so the same command also works from the repository
root as `python3 src/imaging/make_panel.py examples/zif8_vial_5s`.)

## Data caveats

This run is published as a **worked example of the imaging pipeline**, not as
a validated measurement. Specifically:

- **The white reference is clipped.** 43 % of the liquid rows are saturated
  in the metering channel of `ref_white.jpg` (the whole clear supernatant
  region). `make_panel.py` therefore draws no white transmittance curve by
  default and shows the white photograph for visual reference only;
  `--with-white` plots it anyway, as a plain solid line (clipped rows are
  not marked in the plot; their fractions are in the stdout table and the
  draft caption). Every run
  in this measurement batch has a white reference clipped between 62 % and
  90 % over the vial-neck region, which is why this batch should be re-measured
  with a lower white intensity.
- **The 465 nm channel is clipped too.** Its secondary (G) channel saturates
  over 39 % of the liquid rows, again in the clear supernatant. Where the
  465 nm curve sits at T ≈ 1 it is reporting a clipped sensor reading, not a
  measured transmittance. The 625 nm and 525 nm curves are unclipped over
  the full depth range.
- **Old exposure setting.** This batch was photographed before the camera
  exposure was lowered to the reference value of 20 recorded in
  [`../config/camera_reference.json`](../config/camera_reference.json).
  Absolute brightness — and therefore absolute transmittance — is not
  comparable with runs captured after that change; the depth-resolved shape
  within this single run is what the example demonstrates.
- **Wavelengths are nominal.** 625 / 525 / 465 nm are the LED's rated
  values, not independently measured (±10–15 nm).
- **Geometry is auto-detected, not locked.** `geometry_locked` is `false`, so
  the meniscus/body/liquid-bottom rows come from per-run detection on the
  white reference rather than from a locked frame.

For the same reasons this single run is **not** offered as a comparison of
dispensing times: a dispensing-time series would have to be captured under
one fixed exposure and one locked frame, which this batch was not.

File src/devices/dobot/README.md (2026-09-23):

# Dobotロボットアーム制御モジュール

Dobot Magician を `pydobot` ライブラリ経由（シリアル通信）で制御するドライバです。
各インスタンスが独立したシリアル接続を持つため、複数台の Dobot を同時に制御できます。

## ファイル

- `home_dobot.py` — ホーミング CLI（`python -m src.devices.dobot.home_dobot --robot N`）

| ファイル | 役割 |
|---|---|
| `pydobot_controller.py` | `PyDobotController` — 本体 |
| `pydobot_patch.py` | pydobot の通信部分を差し替えるパッチ（応答フレームの検証、完了待ちのタイムアウトと緊急停止での打ち切り） |
| `dobot_config.py` | 速度プリセット・作業位置の定義（`DobotConfig`） |

## 使用例

```python
from src.devices.dobot import PyDobotController

# ポート名を指定して接続（Windows: 'COM12', Linux/macOS: '/dev/ttyUSB0' など）
robot = PyDobotController(port_name='COM12', homing=False)

robot.move_XYZ_abs(200, 0, 100)   # 絶対座標へ移動
robot.move_Z(-50)                 # Z 相対移動
robot.move_XY(20, 30)             # XY 相対移動
robot.move_angle(45)              # ベース（Joint1）角度
print(robot.get_current_position())

robot.disconnect()
```

利用可能なシリアルポートの一覧:

```python
PyDobotController.list_available_ports()
```

## 主なメソッド

| メソッド | 説明 |
|---|---|
| `move_XYZ_abs(x, y, z, r=None)` | 絶対座標へ移動 |
| `move_Z(z_offset)` / `move_XY(dx, dy)` | 相対移動 |
| `move_angle(angle)` | Joint1 の絶対角度 |
| `move_to_initial_pos()` | 初期位置へ |
| `pickup(...)` / `place(...)` | ピックアンドプレース |
| `set_gripper(enabled, on)` / `set_suction_cup(enabled, on)` | エンドエフェクタ |
| `set_speed_preset(name)` | `DobotConfig.SPEED_PRESETS` の速度に切替（直交・Joint の両方） |
| `set_home_params(x, y, z, r)` | ホーム位置の記録 |
| `home(x, y, z, r, timeout_s)` | ファームウェアのホーミング（SetHOMEParams / SetHOMECmd）。完了まで待ち、戻り先を省略すると開始位置に戻る |
| `move_slider(pos)` | リニアレール（0–1000 mm） |
| `move_conveyer(index, speed, time_seconds)` | コンベアベルト |
| `get_current_position()` | `[x, y, z, r]` |
| `force_stop()` | 緊急停止（キュー強制停止・破棄・コンベア停止）。完了待ち中のスレッドも解放する |
| `disconnect()` | 切断 |

## 注意点

- 自動運転の前に、手動で可動域と周囲の安全を確認してください。
- `homing=True` を指定するとホーミング動作で腕が動きます。障害物がないことを確認してください。
  通常は電源投入後に CLI で 1 台ずつ行います:
  `python -m src.devices.dobot.home_dobot --robot 1`（`--mock` で手順だけ確認、
  実機では Enter を押すまで動きません）。戻り先は config.yaml の workspace で事前検証されます。
- 実験用の安全ラッパ（`src/devices/safety/lab_robot.py`）はこのクラスを内部で使い、
  可動域チェックと待機時間を追加します。フロー実行時はラッパ経由で呼び出されます。
- モーターから異音がした場合は直ちに `disconnect()` して物理的な干渉を確認してください。
- 通信の扱い（`pydobot_patch.py`）: 応答はヘッダ `AA AA`・長さ・チェックサム・コマンド ID を
  確認してから使い、送信前に受信バッファを捨てます。一致する応答が 2 秒以内に来なければ
  `DobotReplyError`（`ConnectionError` の派生）。キュー付き移動の完了待ちは既定 60 秒で
  `DobotWaitTimeout`（`PyDobotController(move_timeout_s=...)` で変更可。アームは止めないので
  呼び出し側で `force_stop()` すること）。`force_stop()` の後は待機中の移動が
  `DobotMoveAborted` で即座に戻ります。停止フラグは次の移動指示で下ります。

## 依存関係

- `pydobot`（Copyright 2017 Luis Mesas, MIT License。`pydobot_patch.py` はこのライブラリの `_send_command` / `_send_message` / `_read_message` / `_get_queued_cmd_current_index` / `__init__` を差し替える派生コードです。全文は `THIRD_PARTY_NOTICES.md` 参照）
- `pyserial`

Dobot 純正 DLL（DobotDll）を用いる旧ドライバはライセンス上の理由で本リポジトリには含めていません。

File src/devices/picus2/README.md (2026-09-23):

# Picus2電動ピペット制御モジュール

このモジュールは実験自動化システムにおいてPicus2電動ピペットを USB シリアルまたは Bluetooth 経由で制御するためのクラスと関数を提供します。

## 概要

`picus2_controller.py`はPicus2電動ピペットを操作するための非同期インターフェースを提供します。主な機能には以下が含まれます：

- Bluetooth接続管理
- ボタン操作のエミュレーション
- 液体の吸引・吐出
- チップの排出
- 液体の完全排出（ブローアウト）
- 液体の混合

このモジュールは`asyncio`と`bleak`ライブラリを使用した非同期通信を採用しています。

## 使用方法

### 基本的な使用例

```python
import asyncio
from picus2.picus2_controller import Picus2Controller, Buttons

async def main():
    # Picus2コントローラーの初期化（BluetoothMACアドレスを指定）
    picus = Picus2Controller("XX:XX:XX:XX:XX:XX")
    
    # 接続
    await picus.connect()
    
    try:
        # モーターモードを有効化
        await picus.set_motor_mode(True)
        
        # 5mLを吸引（速度5）
        await picus.aspirate(amount=5.0, speed=5)
        
        # 5mLを吐出（速度5）
        await picus.dispense(amount=5.0, speed=5)
        
        # 残液を完全に排出
        await picus.blow_out()
        
        # チップを排出
        await picus.eject_tip()
        
    finally:
        # モーターモードを無効化
        await picus.set_motor_mode(False)
        
        # 切断
        await picus.disconnect()

# 非同期関数を実行
asyncio.run(main())
```

### ボタン操作

```python
# 特定のボタンを押す
await picus.button(Buttons.TRIGGER_BUTTON_POWER)
await picus.button(Buttons.TRIGGER_BUTTON_LEFT)
await picus.button(Buttons.TRIGGER_BUTTON_RIGHT)
```

### 液体混合

```python
# 5回、速度5で3.0mLの液体を混合
await picus.mix(cycles=5, speed=5, amount=3.0)
```

## 主要機能

### 接続管理

- `connect()` - Picus2に接続する
- `disconnect()` - Picus2から切断する
- `send_command(command)` - コマンドを送信する

### ボタン操作

- `button(button, interval)` - 指定したボタンを押す

### モーター制御

- `set_motor_mode(mode)` - モーターモードを設定する

### 液体操作

- `aspirate(amount, speed)` - 液体を吸引する
- `dispense(amount, speed)` - 液体を吐出する
- `blow_out(go_home, speed, delay_ms)` - 液体をすべて排出する
- `mix(cycles, speed, amount)` - 液体を混合する
- `eject_tip()` - チップを排出する

### ユーティリティ

- `calculate_operation_time(amount, speed)` - ピペット操作にかかる時間を計算する
- `wait_until_END_received()` - ENDメッセージが受信されるまで待機する
- `debug_print(message)` - デバッグメッセージを出力する

## ボタン定数

`Buttons`クラスは以下の定数を提供します：

- `TRIGGER_BUTTON_POWER` - 電源ボタン
- `TRIGGER_BUTTON_LEFT` - 左ボタン
- `TRIGGER_BUTTON_MIDDLE` - 中央ボタン
- `TRIGGER_BUTTON_RIGHT` - 右ボタン
- `TRIGGER_BUTTON_TOP` - 上部トリガーボタン
- `TRIGGER_BUTTON_PRESET` - プリセットボタン
- `TRIGGER_BUTTON_TIPEJECT` - チップ排出ボタン
- `UP` - 上方向ボタン
- `DOWN` - 下方向ボタン

## 注意点

### BluetoothMACアドレスの取得

Picus2のBluetoothMACアドレスを取得するには：

1. ピペットのBluetoothを有効にする
2. コンピュータのBluetoothスキャンを使用して検出する
3. デバイス情報からMACアドレスを確認する（例: "XX:XX:XX:XX:XX:XX"）

### 非同期プログラミング

このモジュールはPython `asyncio`を使用した非同期プログラミングを採用しています：

- 全ての操作メソッドは`async def`で定義されており、`await`キーワードで呼び出す必要があります
- メインスクリプトも非同期関数として定義し、`asyncio.run()`で実行する必要があります

### デバッグモード

デバッグが必要な場合は以下のように設定できます：

```python
picus = Picus2Controller("XX:XX:XX:XX:XX:XX")
picus.DEBUG = True  # デバッグ出力を有効化
```

### オペレーション時間

吸引・吐出などの操作は一定時間を要します。`calculate_operation_time()`メソッドは操作にかかる推定時間を計算し、その時間が経過するまで待機します。速度（1-9）と量（mL）に基づいて計算されます。

### エラー処理

コマンドやボタン/トリガーの送信に失敗した場合（`serial.SerialException`、Bleak の例外、ポートが閉じている場合など）は、`Picus2CommandError`（`ConnectionError` の派生）が送出されます。以前は `button()` がこれらの例外を握りつぶして正常終了していたため、吸引/吐出トリガーの失敗が「完了」と記録され、`LabRobot` の保持量が実際と食い違うことがありました。USB 接続でポート生成後の確認に失敗した場合は、ポートを閉じてから例外を伝播します。`Picus2CommandError` は `src.devices.picus2.picus2_controller` から import してください（`except ConnectionError` でも捕捉できます）。

## 依存関係

- `asyncio` - 非同期処理
- `bleak` - Bluetooth Low Energy通信
- `random` - テスト用のランダム値生成
- `time` - 時間計測

## トラブルシューティング

- 接続エラーが発生した場合、Picus2のバッテリーが十分であることと、Bluetoothが有効になっていることを確認してください。
- 「モーターモードを有効にしてください」というエラーが表示された場合、操作前に`set_motor_mode(True)`を呼び出してください。
- 操作が完了しない場合、操作時間の計算が不正確な可能性があります。実際の操作時間に合わせて待機時間を調整してください。

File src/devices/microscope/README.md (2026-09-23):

# USB デジタル顕微鏡（UVC）制御モジュール

USB 接続のデジタル顕微鏡を OpenCV で制御し、実験記録用の静止画を保存する。
論文のセルではサンワサプライ **400-CAM106** を使っている。この機種を含め、
多くの USB 顕微鏡は OS からは UVC（USB Video Class）のカメラとして見えるので、
専用ドライバは要らず、ウェブカメラと同じ `cv2.VideoCapture` で扱える。

## ファイル

- `microscope_controller.py` — `MicroscopeController`（`WebcamController` を継承）: 映像（UVC）
- `um22_serial.py` — `UM22SerialController`: 制御 MCU とのシリアル通信（LED の ON/OFF・明るさ、フォーカスモーター、状態・型番の読み出し）

## ウェブカメラ用ドライバとの違い

| 項目 | `WebcamController` | `MicroscopeController` |
|---|---|---|
| 保存先 | `captured_images/` | `microscope_images/` |
| 既定解像度 | 1280x720 | **3840x2160**（config.yaml の `shared_devices.microscope_resolution` で変更） |
| 撮影前の読み捨てフレーム | 5 | 10（`warmup_frames`） |
| 露出 | 自動 | 自動。`exposure=` で手動固定も可 |
| 単色フレームの検出 | なし | 警告を出す（`is_uniform`） |

フローからは共有デバイスの `capture_microscope`（撮影）、`microscope_led`（LED）、
`microscope_focus`（焦点）で使う（いずれも `robot_id` 不要）。`SharedDevices` の
`capture_microscope(file_path)`、`set_microscope_led(on, level)`、
`focus_microscope(mode, ...)` がそれぞれ本モジュールのクラスを呼ぶ。

## LED 照明の制御（UM22 系）

400-CAM106 の中身は Vitiny **UM22** で、1 本の USB ケーブルの先に内部ハブがあり、
UVC カメラ（映像）と **CP210x USB シリアル（制御 MCU）** がぶら下がっている。
LED の ON/OFF・明るさ、ズーム、オートフォーカスはこのシリアル経由で制御される。
COM ポート番号は PC ごとに違うので `config.yaml` の `shared_devices.microscope_port` に書く
（空なら LED 制御なし、撮影だけ）。

プロトコル（メーカー製 UM Viewer 1.000.096 を解析し、2026-09-22 に実機で検証）:

| 項目 | 内容 |
|---|---|
| 通信条件 | 115200 bps、8 ビット、パリティなし、**ストップビット 2**、コマンドは **CR 終端** |
| 応答 | `@` + 16 進 2 桁 + CR（例 `@0C`） |
| 読み出し | `R00`+アドレス。0x00 = 状態（`01` 点灯 / `03` 消灯）、0x06 = LED レベル、0x10 = LED モード、0x2F/2E/2D = FW 版数 |
| 型番 | `S00`+アドレス を 0x2C→0x23 の順に 10 回（`UM22TW0100`） |
| 書き込み | `W` + ((アドレス<<8) \| キー \| 値) の 16 進 4 桁 |
| LED ON/OFF | **トグル** `W0159`（UM Viewer の LED ボタンと同じ）。`set_led(on)` は状態を読んで必要なときだけ送る |
| LED 明るさ | `W06`+レベル（出荷時 12。4 で暗く、12 以上で画像が飽和するほど明るい） |
| **注意** | **RTS を立てると MCU がリセットされ、カメラも電源が入れ直される**（約 7 秒）。pyserial は既定で open 時に RTS を立てるので、`rts=False` にしてから開く（本クラスは対応済み） |

## 焦点合わせ（フォーカスモーター）

| 項目 | 内容 |
|---|---|
| レンズ位置の読み出し | `R0009`（上位）と `R000A`（下位）。実機で 346〜1766 を観測、出荷時 1568 |
| 動作中の判定 | 状態レジスタ（`R0000`）のビット 0x04 が立つ。モーターモードは `R0004`（0 待機、2 AF 探索中） |
| AF モード | `W0154` 手動 / `W0155` ワンショット AF / `W0156` 連続 AF |
| 位置指定 | `W18`+上位バイト、`W19`+下位バイト、続けて `W016E`（1755 → 1568 を 4.6 秒で正確に移動） |
| ステップ移動 | `W0152`（in）/ `W0153`（out）で押し、`W0192` / `W0193` で離す。実機では out で位置の値が増える |
| LED レベル書き込みの副作用 | `W06xx` を書くと LED が点灯する。消灯のまま明るさだけ変えるなら `set_led(False, level=...)` |

`autofocus()` は AF を送ってモーターが止まるまで待ち、`(位置, 収束したか)` を返す。
位置や状態が連続して読めないときは `ConnectionError`（通信断を「停止」と誤認しない）。
`request_stop()` で進行中の操作を別スレッドから止められ、例外や割り込みの経路でも
手動モード（`W0154`）を送ってモーターを止める。`step_focus()` は `(位置, 完了したか)` を返す。
**AF は映像ストリームが動いている間だけ働く**（`SharedDevices` はフォーカス中に
フレームを読み続ける）。実機では印刷した数字「4」に対し、全域を一往復して約 40 秒で
位置 1600 に収束した（鮮鋭度 6.0、他の位置では 2〜4）。
**視野にテクスチャが無いと AF は収束せず探索し続ける**（白紙で 60 秒以上）。その場合は
timeout で手動モードに戻して探索を止める。白い対象で画像が飽和する場合は LED レベルを
下げるか露出を短くしてから AF する。
再現性の点では、一度合焦した位置を `get_motor_position()` で読んで記録し、次回は
`goto_position()`（フローでは `mode: "position"`）で同じ位置に戻すのが確実。

```python
with UM22SerialController("COM10") as scope:
    scope.set_led(True, level=4)
    pos, ok = scope.autofocus(timeout_s=60)     # -> (1234, True)
    scope.goto_position(1568)                    # 記録済みの位置へ
    scope.step_focus("out", steps=2)
```

動作確認: `python -m src.devices.microscope.um22_serial COM10 af` / `... goto 1568`

```python
from src.devices.microscope import UM22SerialController

with UM22SerialController("COM10") as scope:
    print(scope.get_model(), scope.get_firmware())   # UM22TW0100 01.03.00
    scope.set_led(False)                              # 消灯
    scope.set_led(True, level=8)                      # 点灯して明るさ 8
```

動作確認: `python -m src.devices.microscope.um22_serial COM10 [on|off]`

## 使用例

```python
from src.devices.microscope import MicroscopeController

with MicroscopeController(camera_index=2) as scope:      # index は環境ごとに違う
    print(scope.get_camera_info())
    scope.capture_and_save("sample_001.jpg")             # -> microscope_images/sample_001.jpg
```

動作確認（接続してカメラ一覧と 1 枚の撮影を行う）:

```bash
python -m src.devices.microscope.microscope_controller 2   # 引数はカメラ index
```

## 解像度とデータ量

実測（DirectShow、2026-09-23）: 3840x2160 ≈ 14 fps、1280x720 ≈ 6 fps、1920x1080 ≈ 2 fps。
4K が最も精細で最も速いので既定にしている。JPEG 1 枚は 0.4〜2 MB（被写体の細かさ次第。
白地に文字だけなら 0.4 MB）なので、1 回の実験で数百枚撮る・ディスクや転送が厳しいときは
`microscope_resolution: "1280x720"` に下げる（1 枚 ≈ 100〜200 KB）。

## 機器の見分け方（400-CAM106）

- デバイスマネージャーでは **UVC Video Device**（VID `EB1A` / PID `279F`、eMPIA 製
  チップ）として見える。ウェブカメラの Logitech C920 は VID `046D`。
- OpenCV の index は列挙順で決まり、PC や USB の挿し口で変わる。Windows では
  `pygrabber` で DirectShow の名前一覧を出すと対応が分かる（上の動作確認コマンドが表示する）。
- 決まった index は `config.yaml` の `shared_devices.microscope_index` に書く。

## 注意点

- 対物側にレンズキャップが付いたままだったり、対象物に密着していると、画像が
  一様な単色になる。`capture_image` はその場合に警告を出す（撮影自体は行う）。
- 400-CAM106 は本体の LED 照明を持つ。明るさは本体側で調整する。
- 露出は OpenCV の `CAP_PROP_EXPOSURE`（Windows では −13〜−1 程度の対数値）。
  自動露出で飽和する場合だけ `exposure=` を指定する。
- 別のアプリ（Windows カメラアプリ、メーカー製 UM Viewer 等）が顕微鏡を開いていると
  フレームを取得できない（接続は成功するが `read()` が失敗し続ける）。
- **メーカー製 UM Viewer は「接続」時に PC の全 COM ポートへ 115200 bps で問い合わせを送る。**
  Dobot・Picus 2・天びんのポートにも送られるので、実験中は UM Viewer を起動しない。
- **緑かぶり（白い対象が緑に写る）の原因と対策。** この機種は電源投入（MCU リセット含む）後、
  ホストが UVC のホワイトバランスコントロールを一度書き込むまで WB ゲインが適用されず、
  R と B が G の半分程度になる（2026-09-22/23 に実機で確認。画像が飽和しているときだけ
  白く見える）。メーカー製 UM Viewer は接続時に WB を書くので直っていた。
  `MicroscopeController.connect()` は WB 5000 K（この機種の既定値）を毎回書き込むので、
  saigen 経由なら対策不要。Media Foundation では WB を書けないため Windows では
  DirectShow で開いている。LED の明るさは原因ではない（WB 適用後はレベル 4 でも中立）。
- **AF は映像ストリームが動いている間だけ収束する**（AF の評価値は映像パイプラインから
  得ている）。`SharedDevices.focus_microscope` はフォーカス中にカメラのフレームを
  読み続けるので、フローから使う分には意識しなくてよい。`UM22SerialController` を
  単体で使うときは、`cv2.VideoCapture` を開いて `read()` し続けながら `autofocus()` を呼ぶ。
- MCU リセット（`reset_mcu()`）はレンズ位置を保ち、LED レベルを出荷時の 12 に戻す。

## 依存関係

- `opencv-python`（`numpy`）
- `pygrabber`（Windows のみ、動作確認コマンドでのカメラ名表示に使用。無くても動く）
- `pyserial`（LED 制御。`um22_serial.py` の中で遅延 import するので、撮影だけなら不要）

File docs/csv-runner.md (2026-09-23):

# Spreadsheet (CSV) input — `src/flow/csv_runner`

The CSV runner is the shortest path from a spreadsheet to a run: the operator opens
one file in Excel, LibreOffice Calc or Numbers, types the volumes, heights, angles and
pipette speeds of a **two-solution mixing** experiment, saves, and runs one command.
No JSON is written by hand and no GUI is needed.

**This is the path used for the paper's ZIF-8 experiments.** The nine reported
batches were executed with the lab's version of this runner (internal
`excel_runner/run_csv.py`, commit `4584333`, in force from 2026-07-02), not with
hand-written or LLM-generated JSON. The runner published here reproduces that
sequence step for step.

The experiment itself is fixed. The runner always performs the same ten steps per
robot (plus two optional ones, 4a and 7a, that are off by default), Robot 1 first and
then Robot 2, and only substitutes the numbers from the CSV:

    for each robot (1, then 2), if its volume is not 0:
        1  move_z(-aspirate_z_descent_mm)     lower onto its source vessel
        2  aspirate                           (robot*_volume_mL, aspirate_speed)
        3  move_z(+aspirate_z_descent_mm)     rise
        4  rotate_relative(angle, "low")      swing over the vial on the balance
        4a move_radial(robot*_dispense_radial_mm)   only if the offset is not 0
        5  move_z(-dispense_z_descent_mm)     lower into the vial
        6  tare_scale(delay=1.0)              tare with the tip already lowered
        7  dispense                           (robot*_volume_mL, robot*_dispense_speed)
        7a blow_out(speed = dispense speed, 3 s)    only if blow_out_after_dispense
        8  measure_weight                     read the mass BEFORE the tip rises
        9  move_z(+dispense_z_descent_mm)     rise
       10  go_home                            the home move also undoes the rotation

    once, only if capture_photo is TRUE:
        capture_and_save                      photograph the vial

Three details of that order are easy to get wrong and are worth stating explicitly:
the balance is tared **after** the tip is already down in the vial, not before the arm
moves; the mass is read **before** the tip rises, so no vibration from the Z move
enters the reading; and there is **no `rotate_relative` back** — `go_home` returns the
arm. The photograph, the radial offset and the blow-out are not part of the historical
sequence: `capture_photo`, `robot*_dispense_radial_mm` and `blow_out_after_dispense`
are off by default, so the default run is exactly the sequence the paper's batches
used, and a sheet that turns them on reproduces the lab's current procedure (see
"Dispense-position offset and blow-out" below).

`examples/zif8/zif8_two_solution_mixing_speed*.json` are the JSON equivalents of this
sequence (plus one closing photograph); see
[`examples/zif8/README.md`](../examples/zif8/README.md).

Anything else — stirring, imaging in the middle of a run, loops, three robots, a
different order — is a JSON flow; see
[`docs/experimental-flow.md`](experimental-flow.md).

## The CSV

`parameter,value,note` — one row per parameter, and the `note` column is free text for
the operator. Row order does not matter. A row whose `parameter` cell is empty or
starts with `#` is a comment and is ignored, so a lab can add its own notes that way.
Every other row must name one of the parameters below **exactly once**: an unknown
name (typically a typo such as `robot1_volume_ml`, which would otherwise leave the
real row at its default) and a parameter given twice are both errors, reported with
their line number in the file (the header is line 1). The optional rows listed below
may still be left out. Copy the published example to your own working file:

```bash
cp src/flow/csv_runner/control.example.csv src/flow/csv_runner/control.csv
```

`control.csv` is gitignored: it holds one lab's numbers, not a published setting.

| `parameter` | Type | Range | Meaning |
|---|---|---|---|
| `robot1_volume_mL` | float | 0, or 0.5–10 | Robot 1 aspirate/dispense volume. **0 skips Robot 1 entirely**; any other value must be at least the pipette wrapper's minimum of 0.5 mL |
| `robot2_volume_mL` | float | 0, or 0.5–10 | Robot 2 aspirate/dispense volume. **0 skips Robot 2 entirely**; otherwise at least 0.5 mL |
| `aspirate_z_descent_mm` | float | 0.1–200 | Z descent onto the source vial before aspirating |
| `dispense_z_descent_mm` | float | 0.1–200 | Z descent onto the vial on the balance before dispensing |
| `aspirate_speed` | int | 1–9 | Pipette speed used for aspiration by both robots. Optional row; **1** if absent |
| `robot1_dispense_speed` | int | 1–9 | Robot 1 pipette speed for dispensing (1 slowest, 9 fastest) |
| `robot2_dispense_speed` | int | 1–9 | Robot 2 pipette speed for dispensing |
| `robot1_angle_deg` | float | −360–360 | Robot 1 base rotation from the source vial to the balance |
| `robot2_angle_deg` | float | −360–360 | Robot 2 base rotation from the source vial to the balance |
| `robot1_dispense_radial_mm` | float | −100–100 | Radial offset of Robot 1's dispense position, applied after the rotation and before the Z descent; negative = towards the base. Optional row; **0** if absent |
| `robot2_dispense_radial_mm` | float | −100–100 | Same for Robot 2. Optional row; **0** if absent |
| `blow_out_after_dispense` | bool | TRUE/FALSE | Blow out the tip after dispensing, before the mass is read (same speed as the dispense, 3 s). Optional row; **FALSE** if absent |
| `capture_photo` | bool | TRUE/FALSE | Photograph the vial once at the end of the run. Optional row; **FALSE** if absent |

The ranges above mirror the constraints in `src/flow/schema.py`. Every value is
converted and range-checked **before any device is opened**, and all problems in the
sheet are reported at once, so a typo can never reach the hardware.

Being inside these ranges is not the same as being safe in *your* cell: the generated
steps go through the same **workspace preflight** as a JSON flow (`run_flow.run_preflight`,
before any device is opened, with `--validate-only` too; a violation exits with code 3).
The fixed sequence consists only of relative moves, which the preflight lists as
"unverified until run", so in practice they are checked move by move, against the `workspace` limits in `config.yaml`
by the same `WorkspaceValidator` that guards the JSON flows (in `--mock` too). Set
those limits for your own bench before a real run — see
[`docs/setup.md`](setup.md).

### Aspiration speed

In the lab version there was no `aspirate_speed` row at all: aspiration used the code
constant `ASPIRATE_SPEED = 1`, and that is the speed at which every ZIF-8 batch in the
paper aspirated. (The note column of the lab's sheet read "aspiration is always 5";
that note was stale and never affected the runs — the code, not the note, set the
speed.) Here it is an ordinary CSV parameter, `aspirate_speed` (1–9), applied to both
robots and written into the generated `aspirate` steps and into `results.csv` with
everything else. **Its default is 1**, so a sheet that leaves the row out reproduces
the historical behaviour exactly; the CSV rows `robot*_dispense_speed` apply only to
dispensing, which is the variable the published runs compare (1 / 5 / 9).

### Dispense-position offset and blow-out

Two optional rows reproduce the additions the lab runner gained after the paper's
batches (lab commit fc68096). `robotN_dispense_radial_mm` inserts a `move_radial`
step right after the rotation, before the Z descent: on a fixture where the vial on
the balance does not sit exactly on the rotation arc, a negative value pulls the tip
towards the base and a positive one pushes it outwards. `blow_out_after_dispense`
inserts a `blow_out` step (piston to its end and back, at the dispense speed, 3 s)
between the dispense and the weighing, so that liquid left in the tip is counted in
the measured mass. Both are off by default, and with both off the generated steps are
identical to the historical sequence. The extra moves go through the same schema and
workspace checks as every other step.

### Validation, an addition over the lab version

Unlike the lab version, which called the device layer directly, the published runner
first assembles the steps as data and **validates them against the flow schema
(`ExperimentWorkflow` in `src/flow/schema.py`) and against the workspace limits in
`config.yaml`** before anything moves — the same two checks that guard a JSON flow, in
`--mock` as well as in a real run. A value that is inside the CSV's own parameter
range but outside your cell (a 200° rotation, say) therefore fails before the arm is
commanded rather than during the run.

## Running

```bash
# dry run: no hardware, every step logged, recording always off
python -m src.flow.csv_runner.run_csv --mock

# check the sheet and the generated step list without running anything
python -m src.flow.csv_runner.run_csv --validate-only

# real run, using src/flow/csv_runner/control.csv and the ports in config.yaml
python -m src.flow.csv_runner.run_csv

# a different sheet, e.g. one per condition
python -m src.flow.csv_runner.run_csv --csv sheets/zif8_speed9.csv

# real run without sensor-CSV/video recording, dispensing ethanol
python -m src.flow.csv_runner.run_csv --no-record --liquid-density 0.789
```

Without `--csv`, the runner uses `src/flow/csv_runner/control.csv` if it exists and
falls back to the published `control.example.csv` if it does not — so `--mock` works in
a fresh clone.

| Option | Meaning |
|---|---|
| `--csv PATH` | input sheet (default: `control.csv`, else `control.example.csv`) |
| `--mock` | run against simulated devices; recording is always off |
| `--validate-only` | read the sheet, build and schema-check the steps and run the workspace preflight, then stop (no device is opened) |
| `--record` / `--no-record` | sensor-CSV and video recording; on by default for real runs |
| `--camera-index N` | camera used when `capture_photo` is TRUE (default: `CAMERA_INDEX` / `config.yaml`) |
| `--liquid-density X` | density in g/mL used to turn dispensed volume into expected mass (default 1.0) |
| `--robot1-dobot`, `--robot1-picus2`, … `--scale-port` | per-run port overrides, exactly as in `run_flow.py` |
| `-v` | debug logging |

Ports come from the same place as every other runner: command-line flag → environment
variable (`.env`) → `config.yaml` → built-in defaults.

Ctrl+C triggers the same **emergency stop** as a JSON run (queue force-stopped, no
further motion commanded, devices disconnected, run recorded as `aborted`).

## Where the results go

A CSV run leaves behind exactly what a JSON run leaves behind, in the same place:

    logs/<YYYY-MM-DD>/two-solution mixing (CSV input)_<timestamp>/
        run.log                  full log of the run
        measurements.csv         one row per step (weights included)
        summary.md               human-readable report
        metadata.json            status, execution mode (mock/real), robots used,
                                 counts, sensor-recording ownership
        dispense_accuracy.csv    expected vs. measured mass per dispense
        control.csv              a copy of the sheet the run was started from
        generated_flow.json      the exact steps that were executed
        images/                  (empty unless capture_photo is TRUE)

`measurements.csv` has a `mode` column and `summary.md` states the execution mode,
so a mock run can never be mistaken for measured data. Two runs started in the same
second get separate folders (`…_<timestamp>_2`, `_3`, …); a run never writes into an
existing folder. With recording on, the runner stops the dashboard's sensor recording
at the end only if this run started it (`/api/start` answered 200); if a recording
was already running (409) it is left alone, and `metadata.json` records which case
applied (`sensor_recording.started_by_this_run`).

`generated_flow.json` is a normal flow file: it can be re-run with
`python -m src.flow.run_flow <that file>`, which makes a spreadsheet run reproducible
by someone who never sees the spreadsheet.

For convenience, the runner also writes `results.csv` **next to the input sheet**, so
the operator can open the parameters and the two dispensed masses in the same
spreadsheet program:

```
key,value
last_run_at,2025-07-12 10:04:31
robot1_volume_mL,5.0
...
robot1_weight_g,4.98
robot2_weight_g,4.97
log_dir,/…/logs/2025-07-12/two-solution mixing (CSV input)_20250712_100418
```

If `results.csv` is open in the spreadsheet program (Windows locks it), a timestamped
`results_<date>_<time>.csv` is written instead. Both are gitignored.

## How this relates to the JSON flows and the GUI

There are three ways to describe an experiment in this repository; all three converge
on the same validated step list, the same executor, the same safety frame and the same
log folder:

| Path | Input | Best for |
|---|---|---|
| **CSV** (`src/flow/csv_runner`) | a spreadsheet of numbers | repeating *this one* experiment with different values — no software skills needed |
| **JSON** (`src/flow/run_flow`) | a full flow file | any sequence: loops, imaging, stirring, more robots |
| **GUI** (`src/gui`) | browser: cards, presets, natural language, voice | building or editing a flow interactively |

The CSV runner does not re-implement any of this. It builds a Python list of steps,
validates it with `ExperimentWorkflow` (`src/flow/schema.py`), and executes it with
`execute_step()` inside an `ExperimentSession`, recording through `ExperimentLogger`
and `DispenseAccuracyLogger` — the same objects `run_flow.py` uses. A change to the
schema, the workspace validator or the logging therefore reaches the spreadsheet path
automatically.
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

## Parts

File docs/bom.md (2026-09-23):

# Bill of Materials (BOM)

Hardware used in the reference implementation described in the paper. Equivalent
instruments can be substituted; the control drivers in `src/devices/` are written
per-device and can be adapted.

## Instruments

| Item | Model | Qty | Notes |
|---|---|---|---|
| Hot-plate stirrer | IKA RET control-visc | 2 | RT–340 °C, 50–1700 rpm, RS-232/USB. Only stirring and temperature control are used; see the note below before buying this model |
| Robot arm | Dobot Magician | 2 | One per solution to prevent cross-contamination |
| Electric pipette | Sartorius Picus 2 (500–10,000 μL) | 2 | Dispensing speed electronically controlled in 9 steps, about 1–11 mL/s (nominal) |
| Electronic balance | Sartorius BCE822i-1SJP | 1 | Capacity 820 g, readability 0.01 g |
| Web camera (process monitoring) | Logitech C920n | 1 | Fixed above the system |
| Web camera (appearance imaging) | Logitech C920n | 1 | Part of the imaging system (`src/imaging/`) |
| USB digital microscope | Sanwa Supply 400-CAM106 (a Vitiny UM22) | 1 | Close-up photos of the product (`capture_microscope`) and LED on/off/brightness (`microscope_led`). One USB cable: UVC camera + CP210x serial for the control MCU. Optional |
| Light | NEEWER RGB62 | 1 | White/red/green/blue illumination, controlled over Bluetooth LE (`src/imaging/`) |
| IoT sensor board | Raspberry Pi Zero WH + Waveshare Environment Sensor HAT | 1 | Temperature, humidity, illuminance, UV, VOC, 3-axis acceleration and angular velocity (magnetometer not read; see `src/monitoring/README.md`) |
| Control PC | — | 1 | Connects to all devices via Wi-Fi or USB |

**Note on the hot-plate stirrer.** The RET control-visc has a built-in weighing
function, but it is of no use for this platform: IKA specifies a weighing range of
10–5000 g with an accuracy of ±(0.3 % + 2) g, so a 5 g dispense would carry an
uncertainty of about ±2 g. All mass measurements in SAIGEN are therefore
made with the electronic balance, and the driver in `src/devices/ika/` only uses the
stirring and temperature commands (IKA NAMUR command set over RS-232/USB). Any IKA
plate with that interface is sufficient; the **IKA Plate (RCT digital)** (RT–310 °C,
50–1500 rpm, RS-232 and USB, same NAMUR commands) is the cheaper choice we would
recommend for a new build. Japanese list prices on ika.com in September 2026:
RET control-visc JPY 298,000, IKA Plate (RCT digital) JPY 184,000. We have not yet
run the driver against an RCT digital ourselves; the commands it sends
(`OUT_SP_2`, `OUT_SP_4`, `START_2/4`, `STOP_2/4`, `IN_PV_x`) are documented for both
models, but confirm on your unit with `--mock` first and then a short real test.

## Fabrication

| Item | Model | Notes |
|---|---|---|
| 3D printer | Bambu Lab X1E | Used to print all fixtures in `cad/` |
| CAD software | Autodesk Fusion 360 | Source `.f3d` / `.f3z` files provided in `cad/` |

## Software / AI services

| Component | Used in |
|---|---|
| Gemini 3.5 Flash (Google) | `src/agent/` — control-code and experimental-flow generation |
| whisper-large-v3-turbo (OpenAI) | `src/voice/` — speech-to-text for voice input |
| YOLOv8 (Ultralytics, AGPL-3.0) | `detection/` — optional object detection for process monitoring |

<!-- TODO: add 3D-printing filament type/settings and any wiring or adapters used. -->

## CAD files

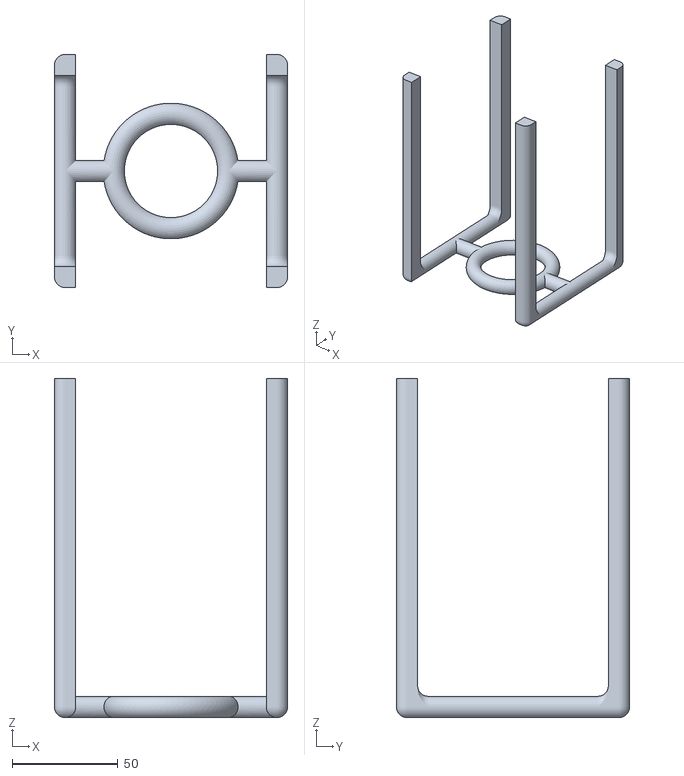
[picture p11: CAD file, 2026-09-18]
cad/vessel-holder/vessel_holder_top_500ml.stl
110.0 x 110.0 x 160.0

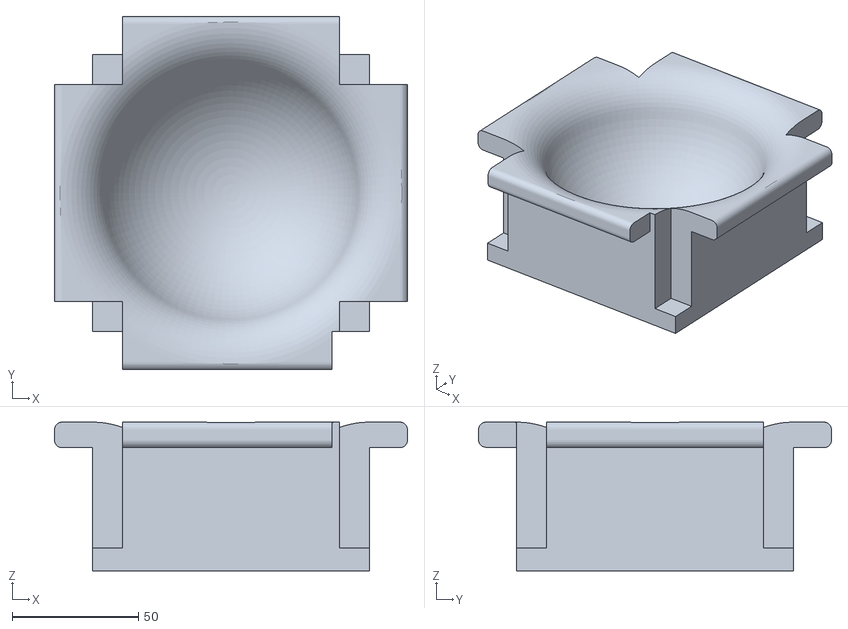
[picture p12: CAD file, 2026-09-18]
cad/vessel-holder/vessel_holder_bottom_500ml.stl
140.0 x 140.0 x 59.0

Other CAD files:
cad/vessel-holder/vessel_holder_bottom_500ml.f3d
cad/vessel-holder/vessel_holder_top_500ml.f3d

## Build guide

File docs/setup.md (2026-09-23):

# Setup guide

From an empty control PC to the first automated dispense. Windows 11 is the
reference platform (the pipette and balance drivers use COM ports); the flow
executor, agent, GUI and voice input also run on macOS/Linux with `/dev/tty*`
device names.

## 1. Hardware

See [`bom.md`](bom.md) for the full list. The minimum for the ZIF-8 demonstration:

- 2 × robot arm (Dobot Magician), USB
- 2 × electric pipette (Sartorius Picus 2, 10 mL), USB (Bluetooth is also supported)
- 1 × electronic balance (Sartorius BCE822i) with RS-232C/USB serial
- 2 × hot-plate stirrer (IKA RET control-visc, or a cheaper IKA plate with the same
  NAMUR serial interface such as the IKA Plate (RCT digital); see `bom.md`) — optional, RS-232C/USB
- 1 × USB webcam
- 1 × USB digital microscope (Sanwa Supply 400-CAM106 or any UVC microscope) — optional,
  used by the `capture_microscope` step
- 3D-printed fixtures from `cad/` (pipette holders on the arm tips, flask holders,
  balance splash guard)

Assembly: mount one pipette on each arm, place the receiving vial on the balance
between the arms, put each solution flask on its stirrer within reach of the
corresponding arm. **One arm + one pipette per solution**, so tips are never
exchanged.

Connect everything to the control PC and note the port of each device
(Windows: Device Manager → *Ports (COM & LPT)*; unplug/replug to identify).

## 2. Software

```bash
git clone https://github.com/YusukeHashimotoLab/saigen.git
cd saigen
python -m venv venv
# Windows
venv\Scripts\activate
# macOS / Linux
source venv/bin/activate
pip install -r requirements.txt
```

Python 3.11–3.13. Optional extras:

- `ffmpeg` on PATH for voice input (`winget install ffmpeg` / `brew install ffmpeg`).
- A CUDA GPU speeds up whisper; CPU works with the int8 model.

## 3. Configuration (`config.yaml` and `.env`)

Two files, with different jobs: `config.yaml` holds the ports and the workspace
limits of your cell; `.env` holds API keys and per-run overrides. Both are
git-ignored.

```bash
cp config.example.yaml config.yaml
cp .env.example .env
```

Edit `config.yaml`:

| Section | Purpose |
|---|---|
| `robots` | `dobot_port` (and `picus2_address`, if that robot has a pipette) per `robot_id` |
| `shared_devices` | `scale_port`, `camera_index`, `microscope_index`, `microscope_port` and `microscope_resolution` of the balance, the photo camera and the digital microscope (camera index for photos, serial port for the LED and focus, capture size; 4K by default, lower it when the image volume gets heavy) |
| `workspace` | X/Y/Z and Joint-1 limits every move is checked against before it is commanded |

If `config.yaml` is absent the tracked `config.example.yaml` is used, and if that is
absent too the built-in defaults in `src/config.py` apply. Sensor-dashboard ports and
the video-recording camera index live in `src/monitoring/config.yaml` (section 8).

Edit `.env`:

| Variable | Purpose |
|---|---|
| `LLM_MODE` | `gemini` (default) or `openai_compatible` |
| `GEMINI_API_KEY` | required for `gemini`; free key from Google AI Studio |
| `LLM_BASE_URL`, `LLM_API_KEY`, `LLM_MODEL` | for any OpenAI-compatible endpoint (local inference server etc.) |
| `ROBOT1_DOBOT_PORT`, `ROBOT1_PICUS2_PORT`, `ROBOT2_*`, `ROBOT3_DOBOT_PORT` | optional per-run override of the `config.yaml` robot ports |
| `SCALE_PORT`, `CAMERA_INDEX`, `MICROSCOPE_INDEX`, `MICROSCOPE_PORT` | optional per-run override of the shared devices |
| `SENSOR_SERVER_URL` | dashboard URL used to start/stop recording (optional) |

`.env` is git-ignored. No key is read from anywhere else. For device ports the
resolution order is: command-line flag > `.env` > `config.yaml` > built-in defaults.

## 4. Check the devices one by one

Each driver has a small self-test; run them with the arm clear of obstacles.

```bash
python -m src.devices.dobot.pydobot_controller          # lists serial ports, connects, reads position
python src/devices/picus2/test_picus2_minimal.py         # edit the port inside the file first
python -m src.devices.scale.scale_controller             # reads the balance
```

The Dobot Magician only knows its joint angles precisely after a **homing** run
(the firmware drives joint 1 to its end stop and re-zeroes the encoders). Do it
once after every power-on, one arm at a time, with the area around the arm clear:

```bash
python -m src.devices.dobot.home_dobot --robot 1 --mock   # rehearse the procedure, no hardware
python -m src.devices.dobot.home_dobot --robot 1          # real: asks for Enter before the arm moves
python -m src.devices.dobot.home_dobot --robot 2
```

The port comes from `config.yaml` (or `.env` / `--port`). `--target` chooses
where the arm returns after homing: `current` (default, the pose it started
from), `zero` (base angle 0°, same radius and height) or `config`
(`DobotConfig.HOME_SETTINGS`). The return pose is checked against the
`workspace` limits before anything is sent, and the tool refuses if it is
outside. The homing sweep itself is decided by the firmware and cannot be
validated, so keep the whole reach clear. Ctrl+C during the sweep is the same
emergency stop as in a flow: the queue is force-stopped and the arm halts.

For the arm, confirm the `workspace` section of `config.yaml` matches your fixtures
before running any flow. Absolute targets (`move_xyz`, `rotate`) are checked
against those limits by a preflight before any device is opened, both with
`--validate-only` and at the start of every run. Relative moves (`move_z`,
`rotate_relative`, `move_radial`) depend on where the arm starts, so they are
checked move by move, **before** each command is sent, in `--mock` mode and in
a real run; a violation aborts the run. If `config.yaml` exists but cannot be
read (invalid YAML, PyYAML missing), every command refuses to start instead of
falling back to the wider built-in defaults.

## 5. First run without hardware

```bash
python -m src.flow.run_flow examples/zif8/zif8_two_solution_mixing_speed5.json --validate-only
python -m src.flow.run_flow examples/zif8/zif8_two_solution_mixing_speed5.json --mock
```

`--validate-only` checks the JSON against the schema (unknown keys, NaN and
out-of-range values are rejected), expands loops and checks every absolute target
(`move_xyz`, `rotate`) against the workspace limits, without opening any device; a
violation exits non-zero with the step number, coordinates and limits. Relative
moves are reported as "unverified until run".
`--mock` runs the whole flow against simulated robots and logs every action; the
workspace limits are enforced move by move, including relative moves, and
recording is always off. A mock run produces the
same `logs/<date>/<flow name>_<timestamp>/` folder as a real one, so you can inspect
`run.log`, `measurements.csv`, `summary.md` and `metadata.json` before touching
hardware.

The mock enforces the same pipette limits as the real wrapper (10 mL capacity,
0.5 mL minimum, no dispensing more than is held, `blow_out` empties the tip), so a
flow that dispenses before it aspirates fails in the mock exactly as it would on
the bench.

**Set the mock start pose to the pose you will start the real run from.** A real
run takes the arm's *current* pose as home and validates every relative move
(`move_z`, `move_radial`, `rotate_relative`) from there. The mock cannot know where
your arm is, so it starts from a fixed pose, X=250, Y=0, Z=150, R=0 by default, and
validates relative moves from that pose. If the real start pose is different, a
mock run can pass a move that the real run rejects, or the other way round.
Read the pose off the arm (DobotStudio, or the start of a previous `run.log`) and
set it either in `config.yaml`:

```yaml
shared_devices:
  mock_start_pose: "200,0,50,0"      # x, y, z, r (mm, mm, mm, degrees)
  # or per robot:
  # mock_start_pose: {1: "200,0,50,0", 2: "0,200,50,90"}
```

or for one run with the environment variable `MOCK_START_POSE=200,0,50,0` (it takes
precedence over `config.yaml`). Joint 1 is derived from X and Y, as on the arm. An
unparsable value stops the mock run instead of silently falling back to the default.

Run the test suite too — it needs no hardware:

```bash
pytest tests/
```

## 6. First run with hardware

0. Home each arm once after power-on (`python -m src.devices.dobot.home_dobot
   --robot N`, see §4). Without it the joint angles the firmware reports can be
   off, and vertical `move_z` moves come out slanted.
1. Move each arm by hand (or with the driver self-test) to the pose you want as
   *home*: pipette tip above the flask, clear of everything. The runner captures the
   current pose as home at start-up; `go_home` returns there.
2. Check the reach: run the position-check presets (`src/agent/presets/wdc_2_dispense_robot1.json`
   etc.) — they move without aspirating.
3. Run the flow:

```bash
python -m src.flow.run_flow examples/zif8/zif8_two_solution_mixing_speed5.json \
    --robot1-dobot COM12 --robot1-picus2 COM4 \
    --robot2-dobot COM7  --robot2-picus2 COM5 \
    --scale-port COM9 --camera-index 1
```

Flags override `.env`, which overrides `config.yaml`. Only the robots referenced by
`robot_id` in the flow are initialised.

Press Ctrl+C to stop: this is an **emergency stop** — the Dobot command queue is
force-stopped so the move in progress halts immediately, the queue is discarded, the
conveyor motors and the IKA heater/stirrer are switched off, and no further motion
(not even going home) is commanded before the devices are disconnected.

Every run writes `logs/<YYYY-MM-DD>/<flow name>_<timestamp>/` containing `run.log`,
`measurements.csv` (one row per step, with the weights and image paths),
`summary.md`, `metadata.json`, `images/` and a copy of the flow JSON. Real runs also
record sensor CSV and overhead video by default; pass `--no-record` to skip that.

For the two-solution mixing experiment the parameters can be entered in a spreadsheet
instead of a JSON flow:

```bash
cp src/flow/csv_runner/control.example.csv src/flow/csv_runner/control.csv
python -m src.flow.csv_runner.run_csv --mock     # then without --mock
```

Same validation, same safety frame, same `logs/<date>/…` folder; the dispensed masses
are also written back to `results.csv` next to the sheet. See [`csv-runner.md`](csv-runner.md).

## 7. GUI and the AI agent

```bash
streamlit run src/gui/app.py
```

The browser opens at `http://localhost:8501`. In the sidebar set the ports and
toggle *Mock* on for a dry run. Then either

- pick a preset and press *Run*, or
- describe the experiment in natural language (typed, or spoken with the microphone
  button), let the agent produce the JSON flow, review and edit it in the step
  editor, and press *Run*.

The ports shown in the sidebar are read from `config.yaml` (see §3); edits there apply
to the current browser session only. Pressing *Run* first validates the flow against
`src/flow/schema.py` — a flow that fails is refused and the offending steps are listed,
so nothing is sent to the instruments. The run then goes through the same
`ExperimentSession` as the CLI and produces the same `logs/<date>/<flow>_<timestamp>/`
folder (`run.log`, `measurements.csv`, `dispense_accuracy.csv`, `metadata.json`,
`summary.md`, `images/`), whose path is shown under the progress bar. *Stop* cancels the
run, emergency-stops every robot and disconnects them. In Real mode, if the monitoring
dashboard is running, sensor recording is started and stopped around the run and its
`/api/is_safe` check gates each step. For the statistics of a dispensing run:

```bash
python -m src.gui.analyze_dispense_log logs/<date>/<flow>_<timestamp>
```

## 8. Monitoring (optional)

```bash
pip install -r src/monitoring/requirements.txt
cp src/monitoring/config.example.yaml src/monitoring/config.yaml
python src/monitoring/dashboard/launch_sensor_dashboard.py
```

opens the dashboard at `http://localhost:8000`, receives sensor data from Raspberry Pi
agents over TCP and records CSV/video into `experiment_data/`. Installing the Pi agent
and the network settings are described in `src/monitoring/README.md`.

## Troubleshooting

- **`GEMINI_API_KEY が設定されていません`** — the key is missing from `.env`, or the
  process was started from another directory (`.env` is loaded from the current
  working directory).
- **Pipette does not connect** — the Picus 2 must be switched on and in remote mode;
  the wrapper retries three times. On Bluetooth, pass the MAC address instead of a
  COM port and set `picus2_connection_type="bluetooth"`.
- **`WorkspaceViolationError`** — the target is outside the configured box; adjust the
  flow, or the `workspace` section of `config.yaml`. The message names the axis, the
  target value and the limit it broke.
- **Camera index** — enumeration order differs between machines; try 0, 1, 2. On
  Windows, `python -m src.devices.microscope.microscope_controller` prints the
  DirectShow device names in index order, so the webcam and the microscope can be
  told apart (the 400-CAM106 shows up as "UVC Video Device", VID `EB1A`).
- **Microscope image is a single flat colour** — the lens cap is on, the tip is
  pressed against the sample, or the LED ring is off; the driver logs a warning
  in that case but still saves the frame.
- **Microscope image has a strong green cast** — after power-up the 400-CAM106
  applies no white-balance gains until the host writes the UVC white-balance
  control once. `MicroscopeController.connect()` does that (5000 K, through
  DirectShow on Windows), so use the saigen driver rather than a plain OpenCV
  capture; the vendor viewer's *Connect* button has the same effect.
- **Microscope LED does nothing** — `microscope_led` needs `microscope_port`: the
  400-CAM106 exposes a second device, a Silicon Labs CP210x serial port (VID
  `10C4`, S/N `0001`), on the same USB cable. Set that COM port in `config.yaml`.
  Do not run the vendor's UM Viewer during an experiment: on *Connect* it writes
  to every COM port on the PC, including the robots, pipettes and balance.

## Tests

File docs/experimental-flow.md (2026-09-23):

# Experimental flow format

The AI agent outputs experimental procedures as a JSON "experimental flow" — an
intermediate representation connecting the natural-language experimental objective
with the control code actually executed. Constraining the LLM output to structured
JSON suppresses generation variability and enables mechanical validation before
execution.

The schema is defined with Pydantic in [`src/flow/schema.py`](../src/flow/schema.py)
and executed by [`src/flow/executor.py`](../src/flow/executor.py). Run
`python src/flow/schema.py` to print the machine-readable JSON Schema.

## Top level

```json
{
  "name": "human-readable name",
  "description": "what the flow does",
  "steps": [ { "action": "...", ... }, ... ]
}
```

| Field | Type | Required | Notes |
|---|---|---|---|
| `name` | string | yes | |
| `description` | string | no | default `""` |
| `steps` | array | yes | executed in order; each element is one of the actions below |

Every step has an `action` field. Robot actions take `robot_id` (1–3, default 1);
shared-device actions (balance, camera) do not. Unknown fields (e.g. a misspelled
`robotid`), out-of-range values and non-finite numbers (`NaN`, `Infinity`) are
rejected at validation time.

## Actions

### Robot arm (Dobot Magician) — `robot_id` required

| `action` | Parameters | Description |
|---|---|---|
| `move_xyz` | `x`, `y`, `z` (mm) | Absolute move in the arm's Cartesian frame |
| `move_z` | `distance` (mm) | Relative vertical move; positive = up |
| `move_radial` | `distance` (mm) | Relative move along the radius from the base; positive = outward |
| `rotate` | `angle` (deg) | Absolute base (joint 1) rotation |
| `rotate_relative` | `angle` (deg), `speed` (`"low"`/`"normal"`/`"high"`, default `"low"`) | Relative base rotation; positive = counter-clockwise seen from above (toward +Y) |
| `go_home` | — | Return to the home position captured at start-up |
| `move_slider` | `position` (0–1000 mm) | Linear rail (optional accessory) |
| `move_conveyer` | `index` (0/1), `speed` (0–200 mm/s), `duration` (0–300 s) | Conveyor belt (optional accessory) |

### Electric pipette (Sartorius Picus 2) — `robot_id` required

| `action` | Parameters | Description |
|---|---|---|
| `aspirate` | `volume` (0.5 ≤ v ≤ 10 mL), `speed` (1–9, default 5) | Aspirate; the wrapper refuses to exceed 10 mL total |
| `dispense` | `volume` (0.5 ≤ v ≤ 10 mL), `speed` (1–9, default 5) | Dispense; refuses to exceed the held volume |
| `blow_out` | `go_home` (bool, default true), `speed` (1–9, default 1), `delay_ms` (int, default 3000) | Expel residual liquid |

Speed 1 is slowest, 9 fastest (about 1–11 mL/s for a 10 mL tip, from the manufacturer's timing table).
The lower bound of 0.5 mL is the real wrapper's minimum operating volume
(`LabRobot.min_pipette_volume`); the schema enforces it so that a flow the mock
accepts is not rejected on hardware.

### Shared devices — no `robot_id`

| `action` | Parameters | Description |
|---|---|---|
| `tare_scale` | `delay` (0.1–10 s, default 1.0) | Tare the electronic balance |
| `measure_weight` | `stabilization_count` (1–10, default 3) | Read the balance; median of N readings, logged in grams |
| `capture_and_save` | `file_path` (string, `""` = auto-generate) | Capture a webcam image. If no image is saved the step fails (and the run stops) rather than being recorded as `ok`; the same holds for `capture_microscope` |
| `capture_microscope` | `file_path` (string, `""` = auto-generate) | Capture an image with the USB digital microscope (UVC, e.g. Sanwa Supply 400-CAM106); saved into the run's `images/` folder with `_microscope` in the name. Opens only the microscope camera; `microscope_led` opens only its serial port; `microscope_focus` opens both |
| `microscope_led` | `on` (bool, default true), `level` (0–255, optional) | Switch the microscope's LED ring on or off and optionally set its brightness (factory level 12). Needs `microscope_port` in `config.yaml` (the UM22's CP210x serial port) |
| `microscope_focus` | `mode` (`auto` / `position` / `step`, default `auto`), `position` (0–65535, for `position`), `direction` (`in`/`out`) and `steps` (1–100, for `step`), `timeout` (1–300 s, default 60) | Focus the microscope: single-shot autofocus, move the lens motor to a recorded position, or step it. Waits until the motor stops and writes the lens position and whether it converged to the `focus_position` / `focus_converged` columns of `measurements.csv`. Autofocus needs a textured target and a non-saturating LED level; on a blank field it hunts until `timeout` and then falls back to manual mode. For reproducibility, record the position once and replay it with `mode: "position"`. Needs `microscope_port` |

### Utility and control flow

| `action` | Parameters | Description |
|---|---|---|
| `wait` | `seconds` (≥ 0) | Sleep |
| `loop_start` | `loop_id` (string), `count` (1–1000) | Begin a loop |
| `loop_end` | `loop_id` | End the loop with the same `loop_id` |

Loops are expanded into a flat list before execution (`expand_loops`). Nesting is not
supported; a `loop_start` without a matching `loop_end` (or vice versa), or a
`loop_end` with a different `loop_id` inside a loop body, is an error.

## Validation rules

Applied before any device moves:

1. **Schema** — every step must match exactly one action model; types and ranges
   above are enforced by Pydantic.
2. **Loop structure** — `loop_id`s must pair up and must not nest.
3. **Workspace preflight** (`--validate-only` and before every run, no device
   opened) — every absolute target (`move_xyz`, `rotate`) is checked against the
   `workspace` section of `config.yaml`. Relative moves (`move_z`,
   `rotate_relative`, `move_radial`) depend on the start pose and are listed as
   "unverified until run"; rule 5 checks them. The same preflight
   (`run_flow.run_preflight` / `require_preflight`) guards all three runners: the
   CLI (`run_flow.py`, exit code 3), the CSV runner (`run_csv.py`, exit code 3)
   and the GUI (`src/gui/runner.py`, which refuses to start the run and shows the
   offending steps and coordinates).
4. **Pipette volume tracking** (run time, in the safety wrapper) — cumulative
   `aspirate` may not exceed 10 mL; `dispense` may not exceed the volume held.
5. **Workspace limits** (run time, move by move) — `move_xyz` / `move_z` / `rotate*` targets are
   checked against the XYZ box and joint-1 range in the `workspace` section of
   `config.yaml`; a violation raises before the command is sent, aborting the run.
   The same check runs in `--mock` mode, so a flow can be screened for out-of-range
   moves without hardware.

Conventions the agent's system prompt also enforces: Robot 3 (rail robot) carries
no pipette; each loop body and the whole flow end with `go_home`.

## Full example — ZIF-8 two-solution mixing

This is `examples/zif8/zif8_two_solution_mixing_speed5.json` (solution 2 dispensed at
pipette speed 5, nominal ≈1.45 s for 5 mL). The `speed1` and `speed9` variants differ
only in the `speed` of the second `dispense`.

The three files are the **JSON equivalents of the CSV-runner sequence** — the fixed
ten-step-per-robot sequence in [`docs/csv-runner.md`](csv-runner.md) that the paper's
ZIF-8 batches were actually run with — plus one closing `capture_and_save`, which the
CSV runs did not take. They are not the files that were executed for the paper; see
`examples/zif8/README.md`.

Running a flow leaves a record of the run in
`logs/<YYYY-MM-DD>/<flow name>_<timestamp>/`: `run.log`, `measurements.csv` (one row
per step, with the weights read, the nominal pipette duration of each aspirate/dispense
step from the Picus 2 timing table, and the photographs taken), `summary.md`,
`metadata.json`, `images/` and a copy of the flow JSON. The execution mode
(`mock` / `real`) is recorded in `metadata.json` (`mode`), in a `mode` column of
`measurements.csv` and in `summary.md`. Runs started within the same second get
distinct folders (`_2`, `_3`, … suffix). When sensor recording is on, a run stops
only a dashboard recording it started itself (`/api/start` → 200); a recording that
was already running (409) is left running, and `metadata.json` →
`sensor_recording.started_by_this_run` says which. See
[`src/flow/README.md`](../src/flow/README.md).

```json
{
  "name": "ZIF-8 two-solution mixing (solution 2 dispensed at pipette speed 5)",
  "description": "… (see the file)",
  "steps": [
    {"action": "move_z", "robot_id": 1, "distance": -0.1},
    {"action": "aspirate", "robot_id": 1, "volume": 5.0, "speed": 1},
    {"action": "move_z", "robot_id": 1, "distance": 0.1},
    {"action": "rotate_relative", "robot_id": 1, "angle": 90.0, "speed": "low"},
    {"action": "move_z", "robot_id": 1, "distance": -120.0},
    {"action": "tare_scale", "delay": 1.0},
    {"action": "dispense", "robot_id": 1, "volume": 5.0, "speed": 9},
    {"action": "measure_weight", "stabilization_count": 3},
    {"action": "move_z", "robot_id": 1, "distance": 120.0},
    {"action": "go_home", "robot_id": 1},

    {"action": "move_z", "robot_id": 2, "distance": -0.1},
    {"action": "aspirate", "robot_id": 2, "volume": 5.0, "speed": 1},
    {"action": "move_z", "robot_id": 2, "distance": 0.1},
    {"action": "rotate_relative", "robot_id": 2, "angle": -90.0, "speed": "low"},
    {"action": "move_z", "robot_id": 2, "distance": -120.0},
    {"action": "tare_scale", "delay": 1.0},
    {"action": "dispense", "robot_id": 2, "volume": 5.0, "speed": 5},
    {"action": "measure_weight", "stabilization_count": 3},
    {"action": "move_z", "robot_id": 2, "distance": 120.0},
    {"action": "go_home", "robot_id": 2},

    {"action": "capture_and_save", "file_path": ""}
  ]
}
```

Note the order inside each robot's block: the balance is tared only after the tip is
down in the vial, the mass is read before the tip rises again, and `go_home` — not a
second `rotate_relative` — brings the arm back.

Distances and angles are specific to the fixture geometry; see
`examples/zif8/README.md` for how to adapt them.

## Presets

Flows that have been checked on hardware are stored as *presets* in
`src/agent/presets/*.json`. A preset wraps a flow in `{"label", "description",
"template"}` and is offered in the GUI; the agent can also be asked to change only
the parameters of a preset (the step order is kept), which is the recommended way to
derive a new condition from a validated procedure.

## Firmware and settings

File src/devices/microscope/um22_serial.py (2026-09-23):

"""
UM22 系 USB デジタル顕微鏡（サンワサプライ 400-CAM106 など）のシリアル制御

400-CAM106 の中身は Vitiny UM22。1 本の USB ケーブルの先に内部ハブがあり、
UVC カメラ（映像）と CP210x USB シリアル（制御 MCU）がぶら下がっている。
LED 照明の ON/OFF・明るさ、ズーム、オートフォーカスはこのシリアル経由で
制御される（メーカー製 UM Viewer も同じ経路）。映像は
``MicroscopeController``（OpenCV）が担当し、このモジュールは制御側だけを扱う。

プロトコル（UM Viewer 1.000.096 を解析し、2026-09-22 に実機で検証）:

- 115200 bps、8 ビット、パリティなし、**ストップビット 2**
- **RTS を立てると MCU がリセットされ、カメラも電源が入れ直される**（約 7 秒）。
  pyserial は既定で open 時に RTS を立てるので、必ず ``rts=False`` にしてから開く
- コマンドは ASCII、**CR（``\\r``）終端**。応答は ``@`` + 16 進 2 桁 + CR
- 読み出し  ``R00`` + アドレス(16 進 2 桁)     例: ``R0006`` → ``@0C`` (LED レベル 12)
- 文字列    ``S00`` + アドレス                 型番はアドレス 0x2C→0x23 の 10 文字
- 書き込み  ``W`` + ((アドレス<<8) | キー | 値) を 16 進 4 桁
- 状態レジスタ 0x00: 0x01 = LED 点灯, 0x03 = LED 消灯（ビット 1 が消灯）
- LED ON/OFF は**トグル** ``W0159``（アドレス 1, キー 64, 値 25）。
  ``set_led(on)`` は状態を読んでから必要なときだけトグルする
- LED レベルはアドレス 0x06（``W06xx`` で書き込み、出荷時 12）。
  LED モードはアドレス 0x10（0 = 全灯、読み出しのみ対応）
- フォーカス（レンズ）モーター: 位置 = (アドレス 0x09 << 8) | アドレス 0x0A
  （実機で 346〜1766 を観測、出荷時 1568）。状態レジスタのビット 0x04 = モーター動作中、
  アドレス 0x04 = モーターモード（0 待機、2 AF 探索中）。
  AF モード書き込み: ``W0154`` 手動 / ``W0155`` ワンショット AF / ``W0156`` 連続 AF。
  位置指定: ``W18hh`` ``W19ll`` ``W016E``（上位・下位バイトを書いてから移動コマンド）。
  ステップ移動: ``W0152``(in) / ``W0153``(out) を押し、``W0192`` / ``W0193`` で離す。
  AF は視野にテクスチャが無いと収束せず探索し続ける（白紙で 60 秒以上）。

使用例:
    from src.devices.microscope import UM22SerialController

    with UM22SerialController("COM10") as scope:
        print(scope.get_model(), scope.get_firmware())   # 'UM22TW0100', '01.03.00'
        scope.set_led(False)                              # 消灯
        scope.set_led(True, level=8)                      # 点灯して明るさ 8
"""

import logging
import threading
import time
from typing import Optional

logger = logging.getLogger(__name__)

# レジスタ / コマンド定数（UM Viewer の NewUMControl と同じ値）
ADDR_STATUS = 0x00
ADDR_LED_LEVEL = 0x06
ADDR_LED_MODE = 0x10
ADDR_FW = (0x2F, 0x2E, 0x2D)          # major, minor, patch
ADDR_MODEL = tuple(range(0x2C, 0x22, -1))  # 0x2C .. 0x23 の 10 文字
STATUS_LED_OFF_BIT = 0x02
KEY_BUTTON = 64
CMD_LED_TOGGLE = 25                   # WriteValue(1, 64, 25) -> "W0159"
CMD_LED_STEP_UP = 26
CMD_LED_STEP_DOWN = 27
LED_LEVEL_DEFAULT = 12

# フォーカス（レンズ）モーター
ADDR_MOTOR_MODE = 0x04
ADDR_MOTOR_POS_HI = 0x09
ADDR_MOTOR_POS_LO = 0x0A
ADDR_TARGET_POS_HI = 0x18
ADDR_TARGET_POS_LO = 0x19
STATUS_MOTOR_BUSY_BIT = 0x04
KEY_RELEASE = 128                     # "ボタンを離す"（連続動作の停止）
CMD_ZOOM_IN = 16
CMD_ZOOM_OUT = 17
CMD_ZOOM_IN_STEP = 18
CMD_ZOOM_OUT_STEP = 19
CMD_AF_MANUAL = 20
CMD_AF_SINGLE = 21
CMD_AF_CONTINUOUS = 22
CMD_MOTOR_RESET = 30
CMD_GOTO_POSITION = 46
FOCUS_MODES = {"manual": CMD_AF_MANUAL, "auto": CMD_AF_SINGLE, "continuous": CMD_AF_CONTINUOUS}
MOTOR_POS_MAX = 0xFFFF


class UM22SerialController:
    """UM22 系顕微鏡の制御 MCU とシリアルで通信するクラス（LED 制御・状態読み出し）"""

    def __init__(self, port: str = "COM10", baudrate: int = 115200,
                 timeout: float = 0.05, reply_wait: float = 0.35):
        """
        Args:
            port: CP210x の COM ポート（プレースホルダ既定値。config.yaml の
                shared_devices.microscope_port で指定する）
            baudrate: 通信速度（115200 固定でよい）
            timeout: 1 回の read のタイムアウト（秒）
            reply_wait: コマンド送信後に応答を待つ時間（秒）
        """
        self.port = port
        self.baudrate = baudrate
        self.timeout = timeout
        self.reply_wait = reply_wait
        self.ser = None
        #: 進行中のモーター操作（autofocus / goto_position / step_focus）への停止要求。
        #: 別スレッドから request_stop() でセットすると、次のポーリングで
        #: モーターを止めて (位置, False) を返す
        self._stop_requested = threading.Event()

    # ------------------------------------------------------------------
    # 接続
    # ------------------------------------------------------------------
    def connect(self) -> bool:
        """ポートを開く。RTS/DTR は立てない（RTS = MCU リセット）。"""
        try:
            import serial
            s = serial.Serial()
            s.port = self.port
            s.baudrate = self.baudrate
            s.bytesize = 8
            s.parity = "N"
            s.stopbits = 2
            s.timeout = self.timeout
            s.write_timeout = 0.5
            s.rts = False
            s.dtr = False
            s.open()
            self.ser = s
            time.sleep(0.2)
            status = self.get_status()
            if status is None:
                logger.error(f"顕微鏡 MCU ({self.port}) から応答がありません")
                self.disconnect()
                return False
            logger.info(f"✓ 顕微鏡 MCU 接続 ({self.port}): status=0x{status:02X}, "
                        f"LED={'ON' if not status & STATUS_LED_OFF_BIT else 'OFF'}")
            return True
        except Exception as e:
            logger.error(f"顕微鏡 MCU 接続エラー ({self.port}): {e}")
            self.disconnect()          # 開きかけのハンドルを残さない
            return False

    def disconnect(self):
        if self.ser is not None:
            try:
                self.ser.close()
            finally:
                self.ser = None

    @property
    def is_connected(self) -> bool:
        return self.ser is not None and self.ser.is_open

    def __enter__(self):
        if not self.connect():
            raise ConnectionError(f"顕微鏡 MCU に接続できません (port={self.port})")
        return self

    def __exit__(self, exc_type, exc, tb):
        self.disconnect()

    # ------------------------------------------------------------------
    # 低レベル
    # ------------------------------------------------------------------
    @staticmethod
    def frame_read(addr: int) -> str:
        return f"R00{addr & 0xFF:02X}"

    @staticmethod
    def frame_read_string(addr: int) -> str:
        return f"S00{addr & 0xFF:02X}"

    @staticmethod
    def frame_write(addr: int, key: int, value: int) -> str:
        return f"W{((addr << 8) | key | value) & 0xFFFF:04X}"

    @staticmethod
    def parse_value(reply: str) -> Optional[int]:
        """``@0C\\r`` -> 12。応答が無い・形式外なら None"""
        if reply.startswith("@") and len(reply) >= 3:
            try:
                return int(reply[1:3], 16)
            except ValueError:
                return None
        return None

    def _require(self):
        if not self.is_connected:
            raise ConnectionError(f"顕微鏡 MCU が接続されていません (port={self.port})")
        return self.ser

    def transact(self, command: str) -> str:
        """CR 終端でコマンドを送り、reply_wait 秒の間に届いた応答を返す"""
        ser = self._require()
        ser.reset_input_buffer()
        ser.write((command + "\r").encode("ascii"))
        deadline = time.monotonic() + self.reply_wait
        buf = b""
        while time.monotonic() < deadline:
            chunk = ser.read(64)
            if chunk:
                buf += chunk
                if buf.endswith(b"\r"):
                    break
        return buf.decode("ascii", "replace")

    def read_value(self, addr: int) -> Optional[int]:
        return self.parse_value(self.transact(self.frame_read(addr)))

    def read_string(self, addrs) -> str:
        """各アドレスの応答 ``@X`` の 1 文字目を連結して文字列を返す"""
        out = ""
        for a in addrs:
            r = self.transact(self.frame_read_string(a))
            out += r[1:2] if r.startswith("@") and len(r) >= 2 else "?"
        return out

    def write(self, addr: int, key: int, value: int) -> None:
        self.transact(self.frame_write(addr, key, value))

    # ------------------------------------------------------------------
    # 高レベル
    # ------------------------------------------------------------------
    def get_status(self) -> Optional[int]:
        return self.read_value(ADDR_STATUS)

    def get_model(self) -> str:
        """型番文字列（例: 'UM22TW0100'）"""
        return self.read_string(ADDR_MODEL)

    def get_firmware(self) -> Optional[str]:
        parts = [self.read_value(a) for a in ADDR_FW]
        if any(p is None for p in parts):
            return None
        return ".".join(f"{p:02d}" for p in parts)

    def get_led_level(self) -> Optional[int]:
        return self.read_value(ADDR_LED_LEVEL)

    def get_led_mode(self) -> Optional[int]:
        return self.read_value(ADDR_LED_MODE)

    def led_is_on(self) -> Optional[bool]:
        status = self.get_status()
        if status is None:
            return None
        return not (status & STATUS_LED_OFF_BIT)

    def toggle_led(self) -> None:
        """UM Viewer の LED ボタンと同じトグルコマンドを送る"""
        self.write(1, KEY_BUTTON, CMD_LED_TOGGLE)
        time.sleep(0.3)

    def set_led(self, on: bool, level: Optional[int] = None) -> bool:
        """LED を指定状態にする。状態を読み、違うときだけトグルする。

        Args:
            on: True = 点灯, False = 消灯
            level: 併せて設定する明るさ（0-255。出荷時 12）。None なら変更しない

        Returns:
            bool: 最終的な LED 状態（True = 点灯）
        """
        if level is not None:
            self.set_led_level(level)
        current = self.led_is_on()
        if current is None:
            raise ConnectionError("顕微鏡 MCU の状態を読み取れません")
        if current != on:
            self.toggle_led()
            current = self.led_is_on()
            if current != on:
                raise RuntimeError(f"LED を {'ON' if on else 'OFF'} にできませんでした (status bit unchanged)")
        logger.info(f"✓ 顕微鏡 LED {'ON' if on else 'OFF'}" + (f" (level {level})" if level is not None else ""))
        return current

    def set_led_level(self, level: int) -> int:
        """LED の明るさを書き込み、読み返した値を返す（0-255）。

        注意: レベルを書き込むと LED は点灯する（実機で確認）。消灯したまま明るさだけを
        変えたいときは ``set_led(False, level=...)`` を使う（書き込み後に消灯し直す）。
        """
        level = int(level)
        if not 0 <= level <= 255:
            raise ValueError(f"LED level out of range: {level}")
        self.write(ADDR_LED_LEVEL, 0, level)
        time.sleep(0.2)
        back = self.get_led_level()
        if back != level:
            logger.warning(f"顕微鏡 LED レベル書き込み: 要求 {level}, 読み返し {back}")
        return back if back is not None else level

    # ------------------------------------------------------------------
    # フォーカス（レンズ）モーター
    # ------------------------------------------------------------------
    def get_motor_position(self) -> Optional[int]:
        """レンズモーターの現在位置（0-65535）。読めなければ None"""
        hi = self.read_value(ADDR_MOTOR_POS_HI)
        lo = self.read_value(ADDR_MOTOR_POS_LO)
        if hi is None or lo is None:
            return None
        return (hi << 8) | lo

    def get_motor_mode(self) -> Optional[int]:
        return self.read_value(ADDR_MOTOR_MODE)

    def motor_is_busy(self) -> Optional[bool]:
        status = self.get_status()
        if status is None:
            return None
        return bool(status & STATUS_MOTOR_BUSY_BIT)

    #: 連続してこの回数、位置か状態が読めなければ通信断とみなす
    MAX_FAILED_POLLS = 6

    def request_stop(self) -> None:
        """進行中のモーター操作を止めるよう要求する（別スレッドから呼んでよい）"""
        self._stop_requested.set()

    def stop_motor(self) -> None:
        """ベストエフォートでモーターを止める（手動モードに戻す）。例外は握りつぶす"""
        try:
            self.set_focus_mode("manual")
        except Exception as e:
            logger.warning(f"顕微鏡モーターの停止コマンド送信に失敗: {e}")

    def wait_motor(self, timeout_s: float = 60.0, interval_s: float = 0.5,
                   settle_polls: int = 3) -> tuple:
        """モーターが止まるまで待つ。

        「動作中ビットが立っていない」かつ「位置が settle_polls 回連続で同じ」を
        停止とみなす。位置や状態が読めなかったポーリングは停止判定に数えず、
        MAX_FAILED_POLLS 回連続で読めなければ ConnectionError を送出する。
        request_stop() が呼ばれていれば、その時点で (位置, False) を返す。

        Returns:
            (position, stopped): 最後に読めた位置と、timeout 内に止まったかどうか

        Raises:
            ConnectionError: MCU から位置・状態が連続して読めない
        """
        deadline = time.monotonic() + timeout_s
        last = self.get_motor_position()
        same = 0
        failed = 0 if last is not None else 1
        while time.monotonic() < deadline:
            if self._stop_requested.is_set():
                return last, False
            time.sleep(interval_s)
            pos = self.get_motor_position()
            busy = self.motor_is_busy()
            if pos is None or busy is None:
                failed += 1
                same = 0
                if failed >= self.MAX_FAILED_POLLS:
                    raise ConnectionError(
                        f"顕微鏡 MCU ({self.port}) からモーター位置/状態が {failed} 回連続で読めません")
                continue
            failed = 0
            same = same + 1 if (pos == last and busy is False) else 0
            last = pos
            if same >= settle_polls:
                return last, True
        return last, False

    def set_focus_mode(self, mode: str) -> None:
        """AF モードを設定する: "manual" / "auto"（ワンショット）/ "continuous" """
        if mode not in FOCUS_MODES:
            raise ValueError(f"unknown focus mode: {mode!r} (choose from {sorted(FOCUS_MODES)})")
        self.write(1, KEY_BUTTON, FOCUS_MODES[mode])

    def autofocus(self, timeout_s: float = 60.0) -> tuple:
        """ワンショット AF を実行し、モーターが止まるまで待つ。

        視野にテクスチャが無いと収束せず探索し続ける。timeout 内に止まらなければ
        手動モードに切り替えて探索を止め、(位置, False) を返す。

        Returns:
            (position, converged)
        """
        self._stop_requested.clear()
        self.set_focus_mode("auto")
        time.sleep(0.5)
        try:
            pos, stopped = self.wait_motor(timeout_s)
        except BaseException:
            self.stop_motor()          # 通信断や割り込みでも探索を続けさせない
            raise
        if not stopped:
            why = "停止要求" if self._stop_requested.is_set() else f"{timeout_s:.0f}s 以内に収束しません"
            logger.warning(f"顕微鏡 AF: {why}（位置 {pos}）。手動モードに戻します")
            self.set_focus_mode("manual")
            time.sleep(0.5)
            self._stop_requested.clear()
            pos, _ = self.wait_motor(10.0)
            return pos, False
        logger.info(f"✓ 顕微鏡 AF 完了: レンズ位置 {pos}")
        return pos, True

    def goto_position(self, position: int, timeout_s: float = 40.0) -> tuple:
        """レンズモーターを指定位置へ動かして止まるまで待つ。

        Returns:
            (position, reached): 最終位置と、要求位置に一致したか
        """
        position = int(position)
        if not 0 <= position <= MOTOR_POS_MAX:
            raise ValueError(f"motor position out of range: {position}")
        self.write(ADDR_TARGET_POS_HI, 0, (position >> 8) & 0xFF)
        time.sleep(0.02)
        self.write(ADDR_TARGET_POS_LO, 0, position & 0xFF)
        time.sleep(0.02)
        self._stop_requested.clear()
        self.write(1, KEY_BUTTON, CMD_GOTO_POSITION)
        time.sleep(0.3)
        try:
            pos, stopped = self.wait_motor(timeout_s)
        except BaseException:
            self.stop_motor()
            raise
        if not stopped and self._stop_requested.is_set():
            self.stop_motor()
            self._stop_requested.clear()
            pos, _ = self.wait_motor(10.0)
        reached = stopped and pos == position
        if reached:
            logger.info(f"✓ 顕微鏡レンズ位置 {pos}")
        else:
            logger.warning(f"顕微鏡レンズ位置: 要求 {position}, 到達 {pos} (stopped={stopped})")
        return pos, reached

    def step_focus(self, direction: str = "in", steps: int = 1, hold_s: float = 0.3,
                   timeout_s: float = 60.0) -> tuple:
        """ステップ移動を steps 回行う（ボタンを hold_s 秒押して離す）。

        実機観測: "out" で位置の値が増え、"in" で減る（hold_s=0.3 で 1 押し ≈ 6〜14）。
        「離す」コマンドは例外時にも必ず送る。timeout_s は押下ループと停止待ちの
        合計に対する上限で、超えたら残りの押下をやめる。

        Returns:
            (position, completed): 最終位置と、全ステップを送って停止を確認できたか
        """
        if direction not in ("in", "out"):
            raise ValueError(f"direction must be 'in' or 'out', got {direction!r}")
        press = CMD_ZOOM_IN_STEP if direction == "in" else CMD_ZOOM_OUT_STEP
        deadline = time.monotonic() + timeout_s
        self._stop_requested.clear()
        done = 0
        for _ in range(max(1, int(steps))):
            if time.monotonic() >= deadline or self._stop_requested.is_set():
                break
            self.write(1, KEY_BUTTON, press)
            try:
                time.sleep(hold_s)
            finally:
                self.write(1, KEY_RELEASE, press)
            done += 1
            time.sleep(0.2)
        remaining = max(1.0, deadline - time.monotonic())
        pos, stopped = self.wait_motor(min(10.0, remaining))
        completed = stopped and done == max(1, int(steps))
        logger.info(f"✓ 顕微鏡フォーカス ステップ {direction} x{done}/{steps}: レンズ位置 {pos}"
                    + ("" if completed else " (未完了)"))
        return pos, completed

    def reset_mcu(self, wait_s: float = 8.0) -> str:
        """RTS パルスで MCU をリセットする。**カメラも電源が入れ直される**ので、
        映像取得中には呼ばないこと。起動ログ文字列を返す。"""
        ser = self._require()
        ser.reset_input_buffer()
        ser.rts = True
        time.sleep(0.1)
        ser.rts = False
        deadline = time.monotonic() + wait_s
        buf = b""
        while time.monotonic() < deadline:
            buf += ser.read(64)
            if b"boot done" in buf:
                break
        log = buf.decode("ascii", "replace")
        logger.info(f"顕微鏡 MCU リセット: {log.strip()!r}")
        return log


# 動作確認用: python -m src.devices.microscope.um22_serial COM10 [on|off]
if __name__ == "__main__":
    import sys

    logging.basicConfig(level=logging.INFO, format="%(asctime)s - %(levelname)s - %(message)s")
    port = sys.argv[1] if len(sys.argv) > 1 else "COM10"
    with UM22SerialController(port) as scope:
        print("model:", scope.get_model(), " firmware:", scope.get_firmware())
        print("status:", scope.get_status(), " LED on:", scope.led_is_on(),
              " level:", scope.get_led_level(), " mode:", scope.get_led_mode())
        print("motor position:", scope.get_motor_position(), " motor mode:", scope.get_motor_mode())
        if len(sys.argv) > 2 and sys.argv[2] in ("on", "off"):
            scope.set_led(sys.argv[2] == "on")
            print("LED on:", scope.led_is_on())
        elif len(sys.argv) > 2 and sys.argv[2] == "af":
            print("autofocus ->", scope.autofocus(timeout_s=60))
        elif len(sys.argv) > 3 and sys.argv[2] == "goto":
            print("goto ->", scope.goto_position(int(sys.argv[3])))
        elif len(sys.argv) > 2 and sys.argv[2] in ("in", "out"):
            print("step ->", scope.step_focus(sys.argv[2], steps=int(sys.argv[3]) if len(sys.argv) > 3 else 1))

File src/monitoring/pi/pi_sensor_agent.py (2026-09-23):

"""Sensor agent for the Raspberry Pi Zero WH + Waveshare Environment Sensor HAT.

Reads the on-board I2C sensors and pushes a JSON line per sample over TCP to the
control PC running the dashboard (see ``src/monitoring/dashboard/launch_sensor_dashboard.py``).

Sensors read (I2C addresses on the default bus, ``/dev/i2c-1``):

    - BME280   0x76  temperature, humidity
    - TSL25911 0x29  visible+IR light, raw channel-0 count (``lux_raw``, NOT lux)
    - ICM20948 0x68  3-axis acceleration, 3-axis angular velocity
    - LTR390   0x53  UV index (UVI)
    - SGP40    0x59  VOC (raw signal, not converted to an index)

Note: the ICM20948 also contains an AK09916 magnetometer accessible through its
auxiliary I2C bus, but this agent does NOT read it. Only the accelerometer and
gyroscope of the ICM20948 are used.

Note on the UV channel: recordings made before 2026-09-08 were taken with the
LTR390 left in ALS mode, in which the UVS data registers never update, so their
``uvi`` column is 0 throughout. From this version the sensor is initialised in
UVS mode and ``uvi`` carries a UV index (float). The CSV column name is
unchanged, so old files stay parseable — only the semantics changed.

Note on humidity: before 2026-09-23 the BME280 humidity was divided by 1024
twice, so older recordings hold 0-0.098 instead of 0-100 %RH (multiply by 1024
to recover it, to a resolution of 1 %RH). See ``compensate_humidity``.

Note on light: the TSL25911 value was sent as ``lux`` until 2026-09-23, but it
has always been the raw channel-0 (visible + IR) ADC count at the power-on gain
(1x) and integration time (100 ms), not lux. It is now sent as ``lux_raw``; the
dashboard maps the old key of older agents onto the new one.

Failed reads: a sensor whose initialisation or read fails reports ``null`` for
its values (never 0), and every message carries an ``ok`` mapping with one
boolean per sensor. Initialisation of a missing or failed sensor is retried
with exponential backoff (1 s doubling up to 60 s) while the others keep
reporting. The SGP40 reply is CRC-checked and a corrupted word is dropped; the
SGP40 is compensated with the BME280's measured humidity and temperature.

Dependencies are kept minimal on purpose (the Pi Zero has limited resources and
this script should run with nothing beyond the Python standard library plus
``smbus``/``smbus2``): no PyYAML, no third-party sensor drivers.

Configuration (environment variables, all optional except the host):

    SENSOR_AGENT_PC_HOST      Required. Hostname or IP address of the control PC.
                               There is no default — an unset value is treated as
                               a configuration error (see below), so a stale
                               address is never silently used.
    SENSOR_AGENT_PC_PORT      TCP port of the dashboard's sensor listener. Default: 50001.
    SENSOR_AGENT_INTERVAL_S   Delay between samples, in seconds. Default: 0.1.
    SENSOR_AGENT_TOKEN        Optional shared secret. When set, the agent sends
                               ``{"type": "auth", "token": ...}`` as the first
                               line of every connection; it must equal
                               SENSOR_DASHBOARD_PI_TOKEN on the PC.

Command-line arguments ``--host``, ``--port`` and ``--interval`` override the
corresponding environment variables. If neither an env var nor ``--host`` is
given, the agent prints an error and exits with status 1 instead of guessing an
address. It also exits with status 1 when the I2C bus cannot be opened or no
sensor answers at all, so systemd restarts it and the failure is visible.

Usage:

    SENSOR_AGENT_PC_HOST=192.0.2.10 python3 pi_sensor_agent.py
    python3 pi_sensor_agent.py --host 192.0.2.10 --port 50001

Runs as a systemd service in normal operation; see ``sensor-agent.service`` and
``sensor-agent.env.example`` in this directory.
"""
import argparse
import json
import logging
import math
import os
import socket
import struct
import sys
import time

logger = logging.getLogger("pi_sensor_agent")

try:
    import smbus
except ImportError:
    try:
        import smbus2 as smbus
    except ImportError:
        # Allowed on the control PC, where the tests import the pure functions;
        # the agent itself refuses to start without it (see start_agent()).
        smbus = None


def compensate_temperature(adc_t, dig_T1, dig_T2, dig_T3):
    """Bosch BME280 integer temperature compensation (datasheet 4.2.3).

    Returns ``(t_fine, temp)`` where ``temp`` is in 0.01 degC (5123 = 51.23 degC)
    and ``t_fine`` is the fine-resolution value the humidity formula needs.
    Pure integer math, no I/O, so it can be unit-tested without ``smbus``.
    """
    v1 = ((((adc_t >> 3) - (dig_T1 << 1))) * (dig_T2)) >> 11
    v2 = (((((adc_t >> 4) - (dig_T1)) * ((adc_t >> 4) - (dig_T1))) >> 12) * (dig_T3)) >> 14
    t_fine = v1 + v2
    temp = (t_fine * 5 + 128) >> 8
    return t_fine, temp


def compensate_humidity(adc_h, t_fine, dig_H1, dig_H2, dig_H3, dig_H4, dig_H5, dig_H6):
    """Bosch BME280 integer humidity compensation (datasheet 4.2.3), in %RH.

    The reference ``bme280_compensate_H_int32`` returns ``v_x1_u32r >> 12``, an
    unsigned Q22.10 value (47445 = 47445/1024 = 46.333 %RH), so %RH is that
    value divided by 1024. The clamp 419430400 = 100 * 2**22 is 100 %RH before
    the final shift. Before 2026-09-23 this code shifted by 22 (already whole
    %RH) and then also divided by 1024, recording 0-0.098 instead of 0-100.
    """
    vh = t_fine - 76800
    vh = (((((adc_h << 14) - (dig_H4 << 20) - (dig_H5 * vh)) + 16384) >> 15) *
          (((((((vh * dig_H6) >> 10) * (((vh * dig_H3) >> 11) + 32768)) >> 10) + 2097152) * dig_H2 + 8192) >> 14))
    vh = vh - (((((vh >> 15) * (vh >> 15)) >> 7) * dig_H1) >> 4)
    vh = 0 if vh < 0 else vh
    vh = 419430400 if vh > 419430400 else vh
    return (vh >> 12) / 1024.0


# --- SGP40 helpers (pure, testable without a bus) ---------------------------

SGP40_DEFAULT_RH = 50.0     # %RH, Sensirion's default compensation value
SGP40_DEFAULT_T = 25.0      # degC


def _finite(v):
    return isinstance(v, (int, float)) and not isinstance(v, bool) and math.isfinite(v)


def sgp40_crc8(data):
    """Sensirion CRC-8: polynomial 0x31, init 0xFF, no reflection, no final XOR.

    ``sgp40_crc8([0xBE, 0xEF]) == 0x92`` (the datasheet's example).
    """
    crc = 0xFF
    for byte in data:
        crc ^= byte & 0xFF
        for _ in range(8):
            crc = ((crc << 1) ^ 0x31) & 0xFF if crc & 0x80 else (crc << 1) & 0xFF
    return crc


def _word_with_crc(word):
    hi, lo = (word >> 8) & 0xFF, word & 0xFF
    return [hi, lo, sgp40_crc8([hi, lo])]
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

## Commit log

2026-09-18 cad: add the 500 mL vessel holder and a preview gallery
    Add the two-part holder for a 500 mL round-bottom vessel: a base with a
    spherical seat and an upper frame that a robot arm or a lift can hook to
    carry the vessel. Files follow the naming convention of the directory.
    Show every printable part in cad/README.md as a rendered preview that
    links to the STL, which GitHub opens in its 3D viewer, and add an
    assembled view of the vessel holder. The previews are generated by
    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
    [vessel_holder_bottom_500ml.f3d, vessel_holder_bottom_500ml.stl, vessel_holder_top_500ml.f3d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]
2026-09-21 README: add a disclaimer
    The MIT warranty clause covers only the code. State for the whole
    repository that SAIGEN is research software provided as is, that a real
    run moves hardware and handles chemicals under the user's responsibility,
    that the safety layer is not a certified safety system, that generated
    flows and code need review, that the CAD models are untested outside our
    laboratory, and that the project is not affiliated with the instrument
    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
2026-09-22 dobot: add firmware homing (home()) and a home_dobot CLI
    pydobot 1.3.x has no home(), so PyDobotController(homing=True) raised
    AttributeError and failed to connect. Implement home() on the Dobot
    protocol directly (SetHOMEParams ID 30 + SetHOMECmd ID 31, queued), wait
    for the queue index to be reached with a timeout, and route homing=True
    through it.
    Add `python -m src.devices.dobot.home_dobot --robot N`, a port of the
    lab's tools/home_dobot.py: --target current|zero|config, ports resolved
    as CLI > .env > config.yaml, --mock to rehearse without hardware. The
    return pose is validated against the config.yaml workspace limits before
    anything is sent; in real mode nothing is sent until Enter is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
2026-09-22 csv_runner: add the lab's dispense-position offset and blow-out rows
    Two optional CSV rows reproduce the additions the lab runner gained after
    the paper's batches (lab commit fc68096), so the published runner can
    express the lab's current two-solution procedure:
    - robot1/2_dispense_radial_mm (-100..100, default 0): inserts move_radial
    right after the rotation, before the Z descent, for fixtures where the
    vial on the balance is not exactly on the rotation arc.
    - blow_out_after_dispense (TRUE/FALSE, default FALSE): inserts blow_out at
    the dispense speed (3 s) between the dispense and the weighing.
    Both default to off, so a sheet without the rows generates exactly the
    historical ten ste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
    [control.example.csv]
2026-09-23 microscope: add the USB digital microscope (Sanwa 400-CAM106 / Vitiny UM22)
    New shared device with three flow actions, following docs/adding-an-instrument.md:
    - capture_microscope: close-up photo through OpenCV (UVC). Default 4K
    (3840x2160, the sharpest and fastest mode on this unit; configurable via
    shared_devices.microscope_resolution). Images land in the run folder as
    stepNNN_microscope_<time>.jpg.
    - microscope_led: LED ring on/off and brightness over the unit's CP210x
    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
2026-09-23 microscope: fixes from the Codex review of the UM22 support
    External review (Codex gpt-6-astra) of the microscope commit, verified
    finding by finding against the code; the agreed items are fixed here.
    Driver (um22_serial.py): wait_motor no longer treats a lost MCU reply as
    "motor stopped" (invalid polls do not count, 6 consecutive failures raise
    ConnectionError); request_stop() lets another thread stop an autofocus /
    go-to / step in progress; autofocus and goto_position switch the MCU to
    manual mode on any exception so the lens never keeps hunting; step_focus
    sends the button-release in a finally block, honours a timeout and returns
    (position, completed); connect() closes a half-open port o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
2026-09-23 safety: emergency-stop paths, config/preflight hardening, Picus2 errors, humidity
    Phase 1 of the fixes from the repository-wide Codex review (verified
    against the code by Opus subagents). All changes tighten safety; none
    widen a limit.
    Emergency stop
    - GUI Stop calls session.emergency_stop_all() directly from the UI thread
    before cancelling the run task, so it acts even while the event loop is
    blocked in a Dobot move; Stop is idempotent and is re-checked right
    before every step is dispatched.
    - ExperimentSession: a Ctrl+C / cancellation that arrives during the
    go_home_all() recovery now runs emergency_stop_all() before cleanup;
    cleanup tries every device and re-raises only afterwa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
    [pi_sensor_agent.py, picus2_controller.py]
2026-09-23 dobot: bounded waits, reply integrity, stop on homing failure
    Phase 2 (area 1/5) of the fixes from the repository-wide Codex review.
    - pydobot_patch: the post-move wait now finishes on current >= expected,
    gives up after move_timeout_s (60 s) with DobotWaitTimeout, and aborts at
    once with DobotMoveAborted when force_stop() has set the stop flag, so a
    run no longer hangs forever after an emergency stop.
    - Replies are buffered and parsed as frames (AA AA + length + checksum);
    garbage, bad checksums and corrupted lengths are dropped, input is
    flushed before every send, and the reply ID must match the request
    (DobotReplyError otherwise). This closes the path where a late pose reply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
2026-09-23 safety: non-blocking moves, unknown-state tracking, mock parity, SafetyAbort
    Phase 2 (area 2/5) of the fixes from the repository-wide Codex review.
    All changes tighten safety.
    - Every blocking Dobot call (moves, go_home legs, slider, conveyor) runs in
    a worker thread; on cancellation LabRobot sends force_stop() immediately,
    waits for the worker, then re-raises. The first Ctrl+C now stops a move
    instead of waiting for it to finish.
    - After a cancelled or failed move (or any emergency stop) the pose is
    unknown and is re-read from the arm (two matching reads) before the next
    validated move; a moving arm is refused. After a cancelled or failed
    aspirate/dispense/blow-out the held vol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
2026-09-23 runners/GUI: preflight everywhere, mock-by-default GUI, strict CSV, provenance
    Phase 2 (area 3/5) of the fixes from the repository-wide Codex review.
    - The workspace preflight is reusable (run_preflight / require_preflight /
    PreflightError, exit code 3) and runs in the CSV runner and the GUI
    runner before any device is opened.
    - GUI: Mock is the default; a real run needs the "実機で実行する" checkbox
    in the current session plus a confirmation; the execution panel (Stop) is
    drawn before the canvas and the canvas is guarded; JSON import, AI
    generation, the toolbox and canvas edits are disabled during a run; a new
    flow replaces the current one only after it validates; the se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
    [control.example.csv]
2026-09-23 monitoring: ingestion auth, XSS fix, endpoint tokens, sensor nulls, lux_raw
    Phase 2 (area 4/5) of the fixes from the repository-wide Codex review.
    - Sensor ingestion: optional SENSOR_DASHBOARD_PI_ALLOWED_IPS (IPs/CIDR) and
    SENSOR_DASHBOARD_PI_TOKEN (first-line auth from the Pi agent); every
    message is type-checked and malformed lines are dropped without stopping
    the recording. Warns at startup when neither is set.
    - Dashboard page: all hostnames/IPs are escaped (spoofed mDNS names could
    run script as the operator); the missing removeDevice() is added.
    - HTTP API: the token, when set, is required on upload_video, detect_tags,
    zero_tags and clear_zero too; state-changing endpoints r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
    [pi_sensor_agent.py]
2026-09-23 imaging: data-driven captions, camera read-back, macOS device index, BLE errors
    Phase 2 (area 5/5) of the fixes from the repository-wide Codex review.
    - Captions are built from summary.json and per-pixel clip fractions
    measured on the photos; unrecorded values are "unknown" (CLAUDE.md rule 6).
    - Camera settings: every set() is checked and read back; summary.json
    stores the read-back settings before/after the run; acquisition checks
    /api/health and aborts on a stale stream; /api/control writes are refused
    while a run holds the lock unless they carry the run's token.
    - macOS: the uvc-util device index is resolved by camera name (fails when
    missing or ambiguous); the server passes it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
